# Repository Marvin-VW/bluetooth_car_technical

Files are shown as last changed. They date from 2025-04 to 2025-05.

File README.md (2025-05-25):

# 3D-Printed ESP32 RC Car – Complete Project Documentation

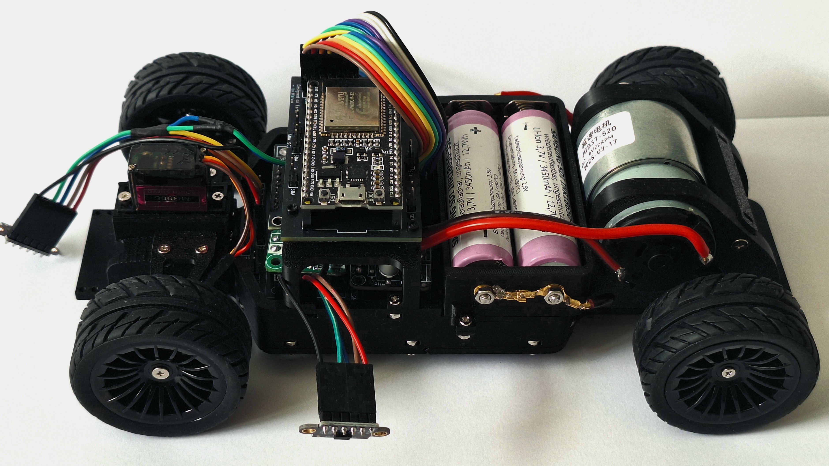
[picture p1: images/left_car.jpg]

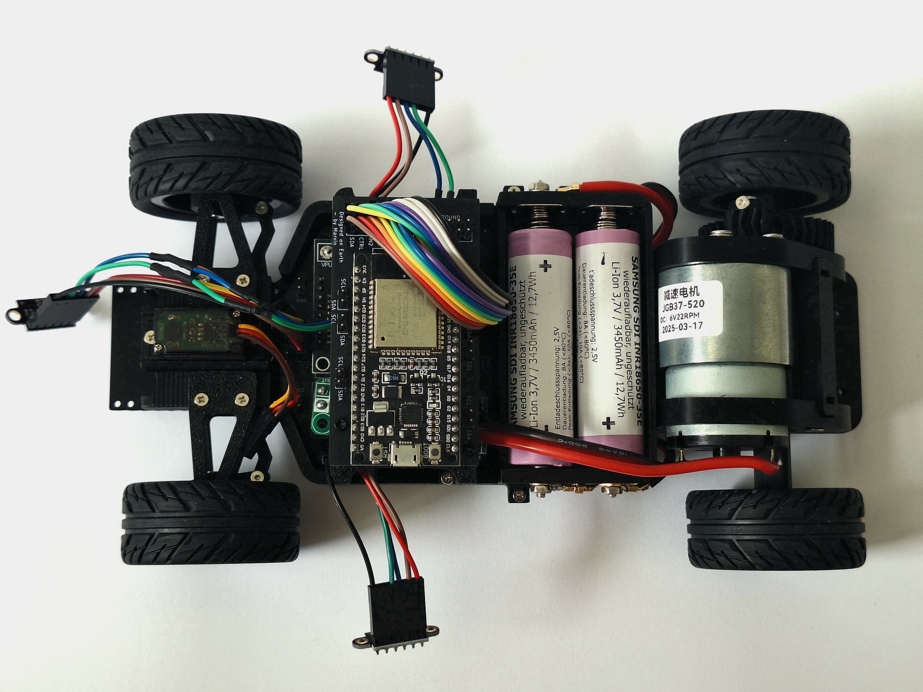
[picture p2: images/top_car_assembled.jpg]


## Project Overview
This project consists of a fully 3D-printed RC car based on an ESP32 controller, designed for remote control via a custom-built app.  
All mechanical parts, electronics (PCBs), and software components are fully self-developed or heavily customized.

The vehicle body is based on a DeLorean model (Back to the Future), which has been modified for integration of custom hardware components and a clear interior view.

---

## Features
- **Drive System**:
    - JGB37-520 Motor connected via an axle with ball bearings
    - Front axle controlled by MG90S servo
- **Distance Sensors**:
    - 3x VL53L0X laser distance sensors connected via I2C bus
- **Camera**:
    - ESP32-CAM module for live video streaming over WiFi
- **Lighting**:
    - WS2812C individually addressable LEDs for headlights, taillights, indicators, brake lights, and reverse lights
- **Battery**:
    - 2x Samsung SDI INR18650-35E 3.7V cells (combined to 7.2V system)
- **Charging**:
    - USB-C PD (Power Delivery) charging at 9V/3A via custom charging module
- **Battery Management System (BMS)**:
    - HX-2S-D20 unit for safe charging/discharging

---

## Mechanical Design
- **Chassis**: Modified base from DKS Basics, adjusted for optimized motor mounts, axle supports, battery placement, ESP32 mounting, and PCB integration.
- **Body**: DeLorean STL, modified for wheel clearance, USB-C charging access, and removal of windows for better visibility of internal components.
- **3D Printed Parts**:
    - Chassis components
    - Gear holders and servo brackets
    - Motor mounts
    - Sensor mounts
    - Battery compartments
    - LED lighting holders

---

## Bill of Materials (BOM)

| Component | Description |
|---|---|
| ESP32 | Main microcontroller |
| JGB37-520 Motor | Drive motor |
| MG90S Servo | Steering servo |
| 3x VL53L0X | Distance sensors (I2C bus) |
| 2x Samsung INR18650-35E | Battery cells |
| INA3221 | Triple current monitor |
| HX-2S-D20 | 2S BMS for battery management |
| ESP32-CAM | Camera module |
| WS2812C LED Strip | Addressable LEDs for lighting |
| Custom Power PCB | Power regulation and distribution board |
| Custom ESP32 PCB | ESP32 interface board |
| Front LED PCBs (x2 variants) | Strip & individual LED board for front lighting |
| Rear LED PCBs (x2 variants)  | Strip & individual LED board for rear lighting |
| 3D Printed Parts | Chassis, body, mounting structures |
| USB-C Charging Module | USB-PD fast charging support |
| Bearings, Gears, Shafts | Mechanical components |

---

## Repository Structure

```bash
/3d-printed-esp32-rc-car
│
├── 3d_printed_parts/             # STL files for chassis and case
│
├── pcbs/
│   ├── power_pcb/                # KiCad files and Gerbers for power management board
│   ├── esp32_pcb/                # KiCad files and Gerbers for ESP32 connection board
│   ├── lighting_pcbs/
│   │   ├── front_strip_version/  # PCB for front LED strip mounting
│   │   ├── front_single_led/     # PCB for front individual LEDs
│   │   ├── rear_strip_version/   # PCB for rear LED strip mounting
│   │   └── rear_single_led/      # PCB for rear individual LEDs
│
├── firmware/                     # (External Link: [ESP32 Firmware Repo](https://github.com/Marvin-VW/bluetooth_car_cpp))
│
├── app/                          # (External Link: [Mobile App Repo](https://github.com/Marvin-VW/spring_rest_todo_app))
│
├── images/                       # Photos, renderings, diagrams
│
└── README.md                     # This file
```

---

## Electronic Architecture

### Main Boards:
- **Power PCB**:
    - Battery management (charging/discharging)
    - 5V and 6.6V regulated outputs
    - INA3221 triple current sensor
    - Connectors for servo, distance sensors, motor
- **ESP32 PCB**:
    - Dedicated ESP32 interface
    - Connection to power PCB via a 2x7 (14-pin) connector

### Lighting Boards:
- **Front LED Boards**:
    - *LED Strip Version*: For easier integration of flexible LED strips (WS2812C-compatible)
    - *Individual LED Version*: For precise placement of discrete WS2812C LEDs
- **Rear LED Boards**:
    - *LED Strip Version*
    - *Individual LED Version*

Each lighting board is tailored to fit into designated 3D printed holders.

---

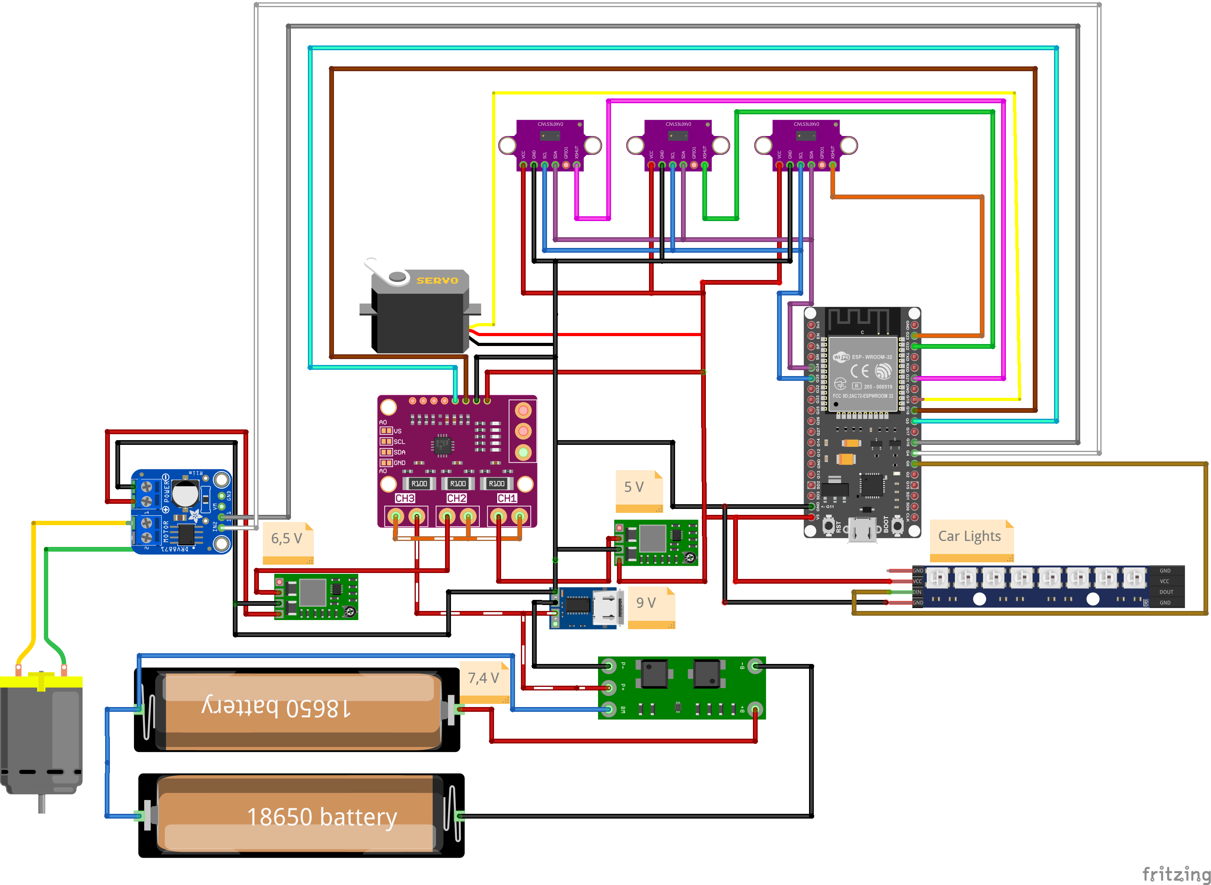
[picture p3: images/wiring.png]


Note: Pins not accurate.

---

## Build and Assembly

1. **3D Print Parts**  
   Print all required STL files using PLA or PETG for maximum durability.

2. **Assemble Electronics**
    - Solder PCBs based on provided KiCad projects.
    - Install the Power PCB, ESP32 PCB, distance sensors, and LEDs.

3. **Mechanical Assembly**
    - Mount motor, servo, and axles with ball bearings.
    - Install batteries, boards, and secure the chassis components.

4. **Install Firmware**
    - Flash the ESP32 using the firmware available in the firmware repository.

5. **App Setup**
    - Install the mobile app to control the car via WiFi.

6. **Testing and Calibration**
    - Test motor, servo, sensors, and LEDs individually before full operation.

---

## License
MIT License

---

## Contributions
Contributions, issues, and feature requests are welcome! Feel free to check the [issues page](#).

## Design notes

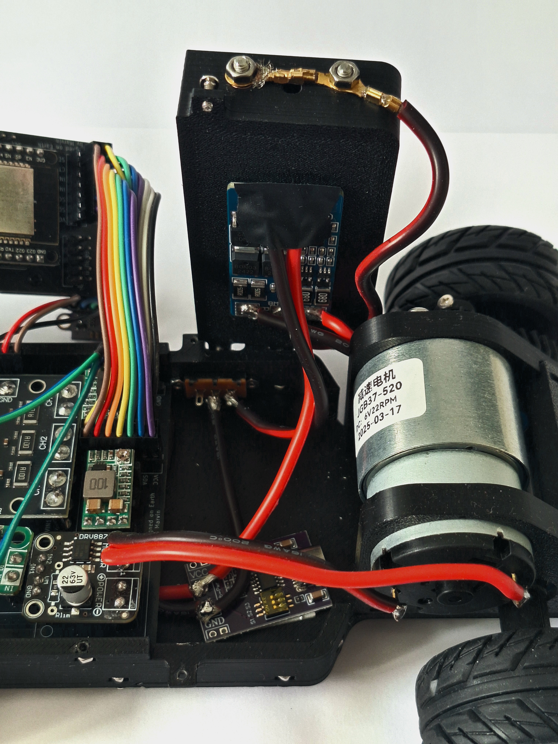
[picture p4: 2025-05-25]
images/battery_car.jpg

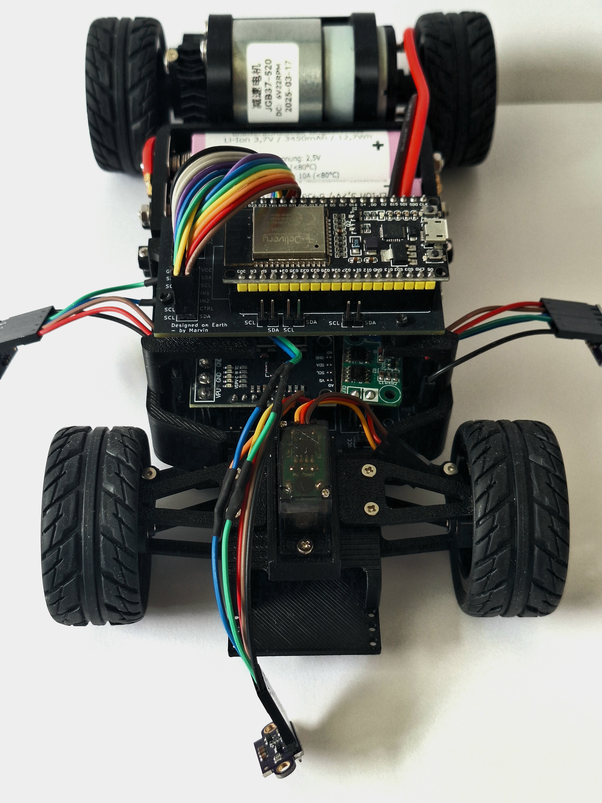
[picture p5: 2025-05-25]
images/front_car.jpg

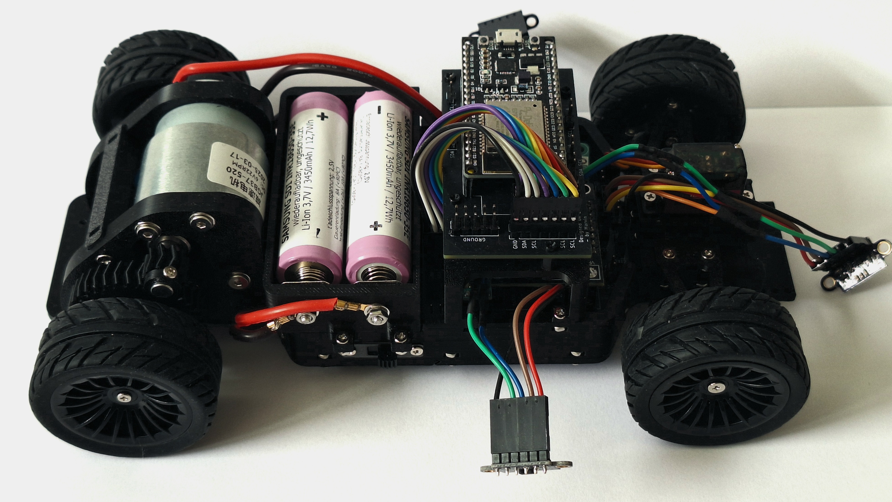
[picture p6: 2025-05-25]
images/right_car.jpg

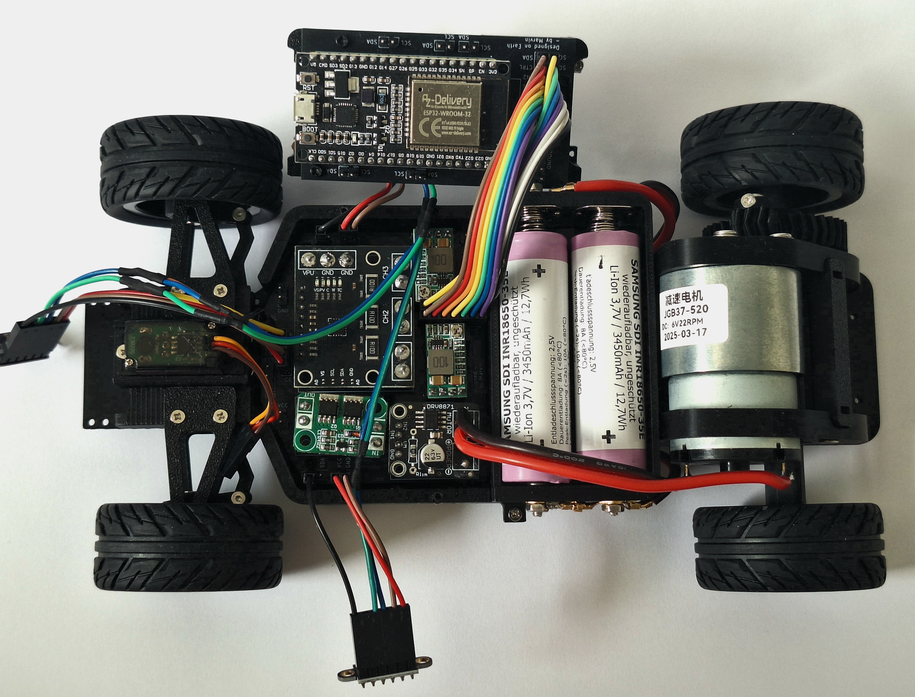
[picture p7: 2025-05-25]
images/top_car.jpg

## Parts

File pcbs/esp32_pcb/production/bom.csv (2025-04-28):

Designator | Footprint | Quantity | Value | LCSC Part #
J1, J3, J4, J5, J6 | PinHeader_1x02_P2.54mm_Vertical | 5 | Conn_01x02_Pin
J2 | PinHeader_2x07_P2.54mm_Vertical | 1 | Conn_02x07_Odd_Even
J7 | PinHeader_2x05_P2.54mm_Vertical | 1 | Conn_02x05_Odd_Even
U1 | MODULE_ESP32-DEVKITC-32E | 1 | ESP32-DEVKITC-32E

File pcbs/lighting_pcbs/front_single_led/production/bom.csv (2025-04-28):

Designator | Footprint | Quantity | Value | LCSC Part #
_2, |  | 2
J2, J3 | PinHeader_1x03_P2.54mm_Vertical | 2 | Conn_01x03
U1, U10, U11, U12, U13, U14, U15, U16, U2, U3, U4, U5, U6, U7, U8, U9 | LED_WS2812C-2020 | 16 | WS2812C-2020

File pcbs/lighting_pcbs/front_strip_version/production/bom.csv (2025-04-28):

Designator | Footprint | Quantity | Value | LCSC Part #
_2, |  | 2
J1, J2, J3, J4, J5, J6, J7, J8 | led_pads | 8 | Conn_01x03_Pin
J10, J9 | PinHeader_1x03_P2.54mm_Vertical | 2 | Conn_01x03_Pin

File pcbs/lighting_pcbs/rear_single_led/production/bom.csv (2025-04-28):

Designator | Footprint | Quantity | Value | LCSC Part #
_2, |  | 2
J1, J3 | PinHeader_1x03_P2.54mm_Vertical | 2 | Conn_01x03_Pin
U1, U14, U15, U16, U17, U18, U19, U2, U20, U3, U4, U5, U6, U7 | LED_WS2812C-2020 | 14 | WS2812C-2020

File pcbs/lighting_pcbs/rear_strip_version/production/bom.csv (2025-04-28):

Designator | Footprint | Quantity | Value | LCSC Part #
J1, J2, J5, J6 | led_pads | 4 | Conn_01x03_Pin
J10, J9 | PinHeader_1x03_P2.54mm_Vertical | 2 | Conn_01x03_Pin

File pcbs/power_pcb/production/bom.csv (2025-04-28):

Designator | Footprint | Quantity | Value | LCSC Part #
_3, _2, |  | 3
J1, J14, J25 | PinHeader_1x04_P2.54mm_Vertical | 3 | Conn_01x04_Pin
J13, J20, J22, J23, J26, J27, J3 | PinHeader_1x02_P2.54mm_Vertical | 7 | Conn_01x02_Pin
J2 | PinHeader_2x07_P2.54mm_Vertical | 1 | Conn_02x07_Odd_Even
J21, J24 | PinHeader_1x03_P2.54mm_Vertical | 2 | Conn_01x03_Pin
U1 | anti_reverse | 1 | ~
U2 | DRV8871 | 1 | ~
U4 | INA3221_Module | 1 | ~

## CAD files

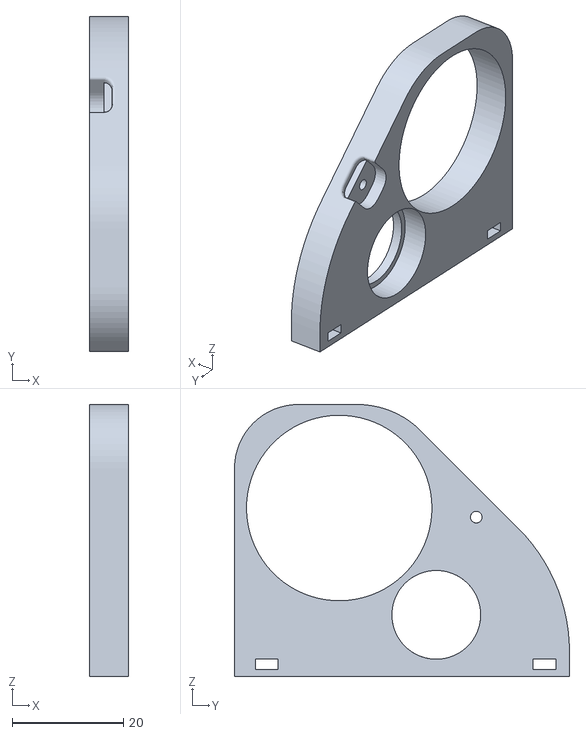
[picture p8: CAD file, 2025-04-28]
chassis/stl/105_Chassis v105_Motor-Frame_L.stl
7.00 x 60.4 x 49.0

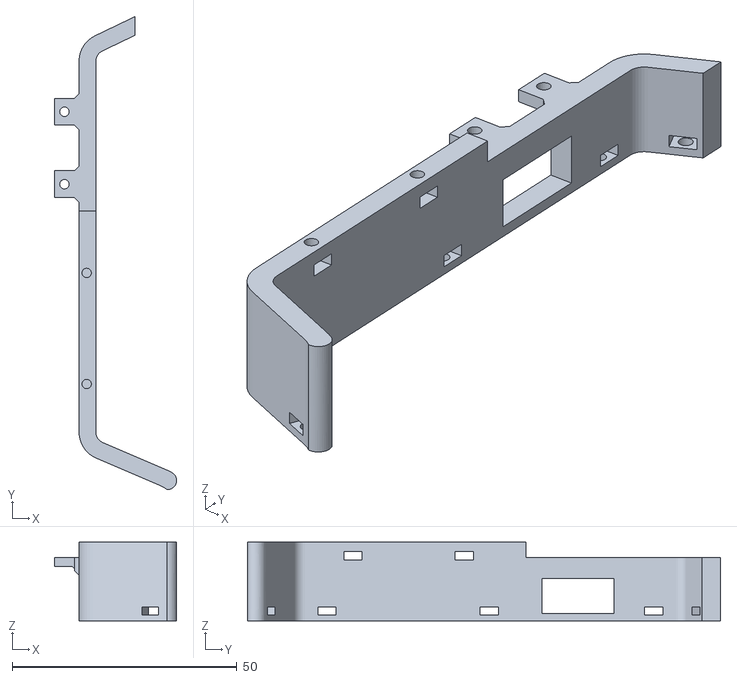
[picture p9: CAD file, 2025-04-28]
chassis/stl/105_Chassis v105_Body_R.stl
27.2 x 105.2 x 17.5

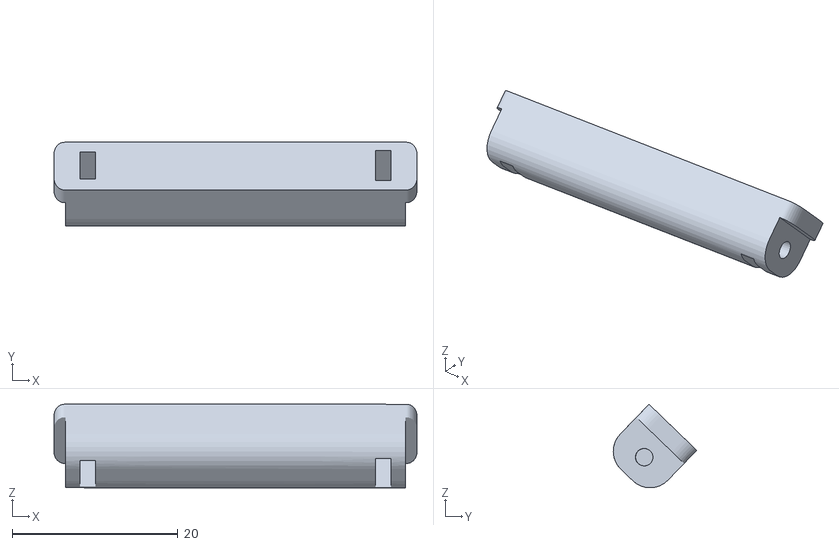
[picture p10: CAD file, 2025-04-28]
chassis/stl/105_Chassis v105_Motor-Frame_Backing.stl
43.8 x 10.1 x 10.1

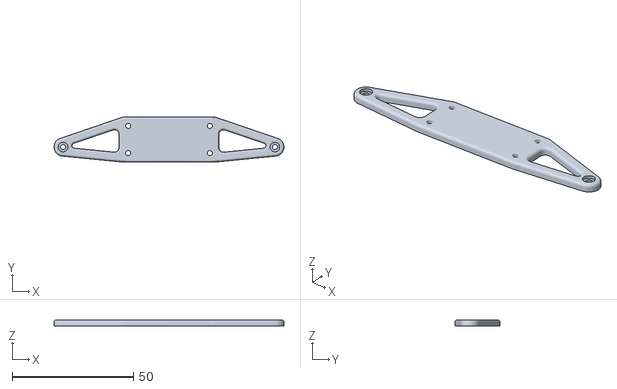
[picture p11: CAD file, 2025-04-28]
chassis/stl/105_Chassis v105_Front-Bars-Lower.stl
95.0 x 18.8 x 2.50

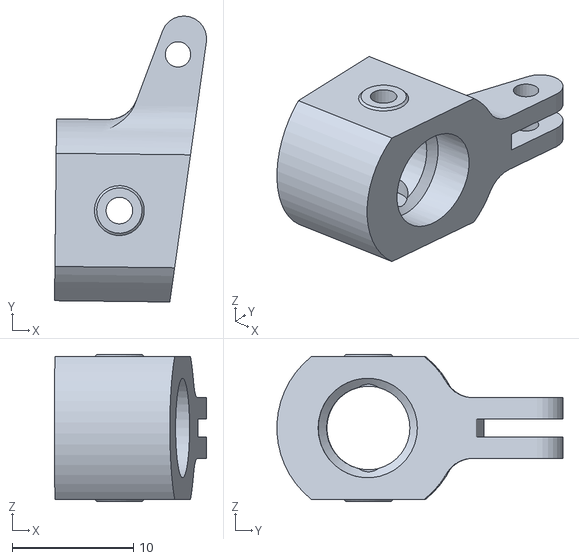
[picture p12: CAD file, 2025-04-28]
chassis/stl/105_Chassis v105_Wheel-Hub_R.stl
12.5 x 23.6 x 12.1

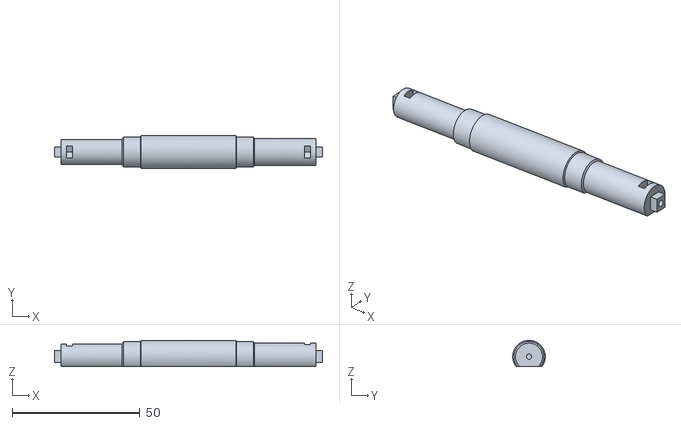
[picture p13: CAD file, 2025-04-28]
chassis/stl/105_Chassis v105_Rear-Axis.stl
105.0 x 12.8 x 10.3

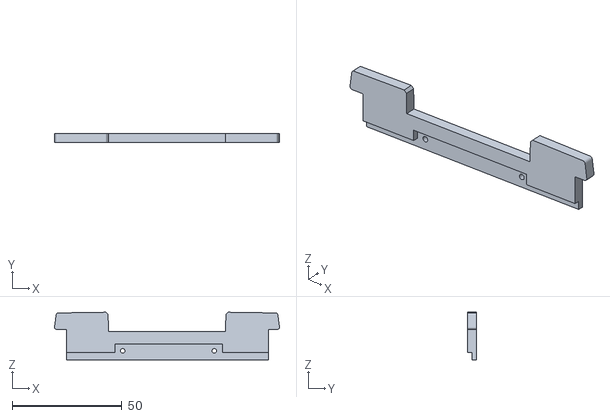
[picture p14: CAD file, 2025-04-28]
chassis/stl/105_Chassis v105_stripe_holder_front.stl
102.7 x 4.00 x 21.7

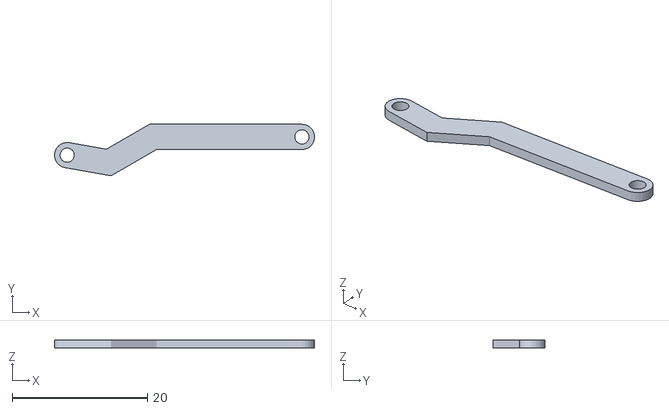
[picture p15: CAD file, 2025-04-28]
chassis/stl/105_Chassis v105_Steering_L.stl
38.4 x 7.62 x 1.25

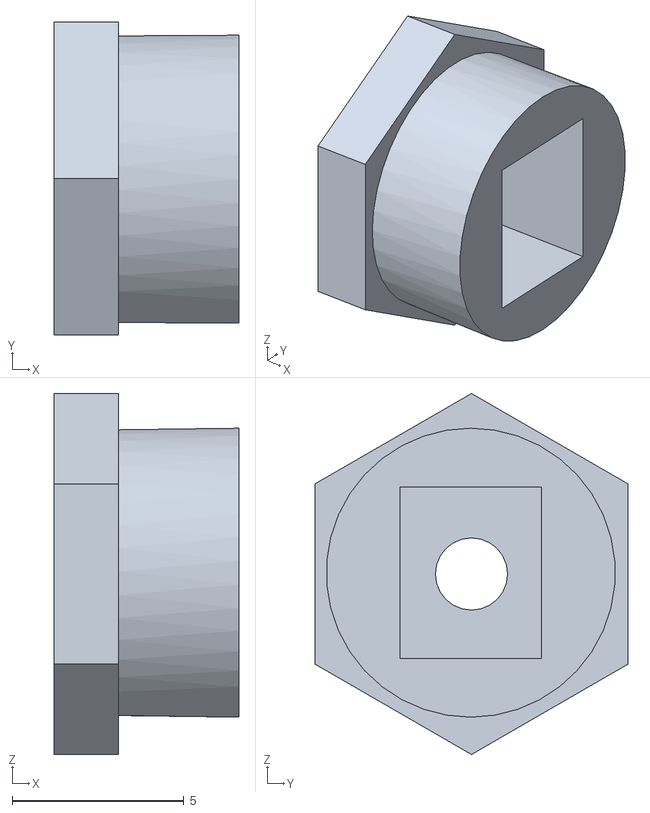
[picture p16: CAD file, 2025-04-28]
chassis/stl/105_Chassis v105_Wheel-Axis_R.stl
5.38 x 9.09 x 10.5

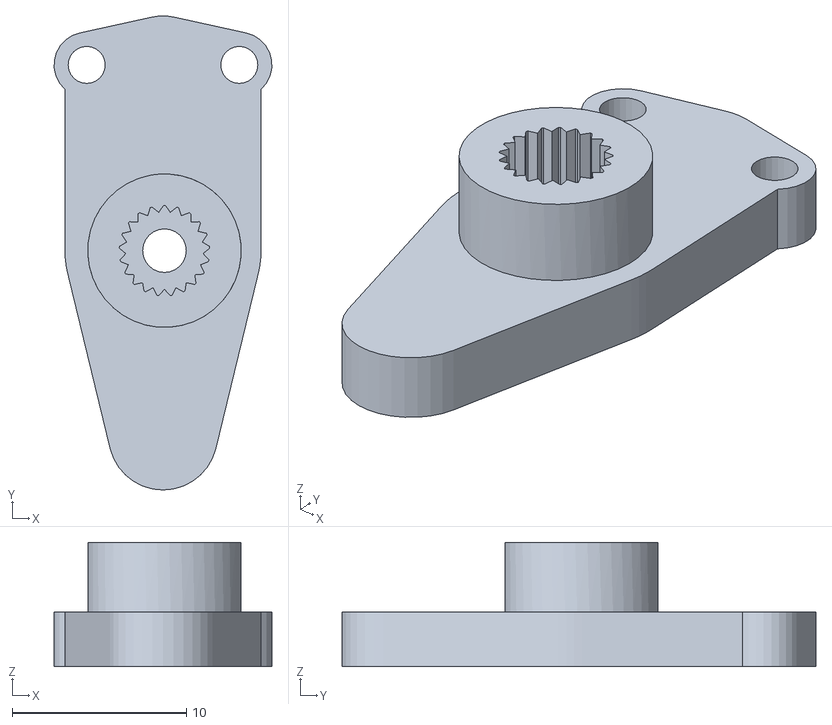
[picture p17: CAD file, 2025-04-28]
chassis/stl/105_Chassis v105_Servo_Horn.stl
12.5 x 27.2 x 7.12

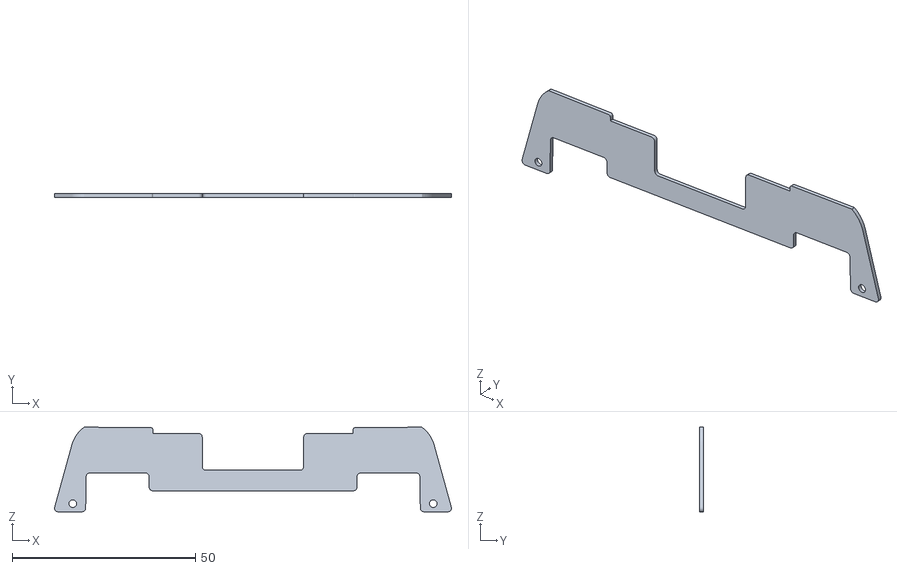
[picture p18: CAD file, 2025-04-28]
chassis/stl/105_Chassis v105_stripe_holder_back.stl
108.3 x 1.00 x 23.1

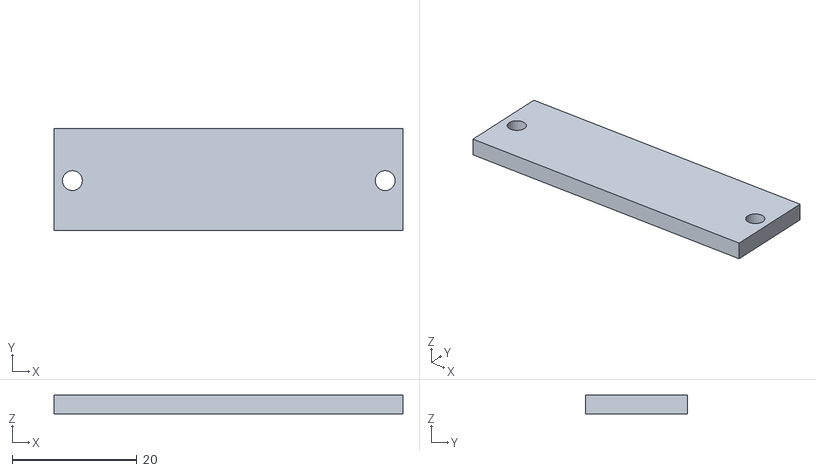
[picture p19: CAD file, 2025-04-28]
chassis/stl/105_Chassis v105_Car_Holder_Front(2).stl
55.9 x 16.4 x 3.00

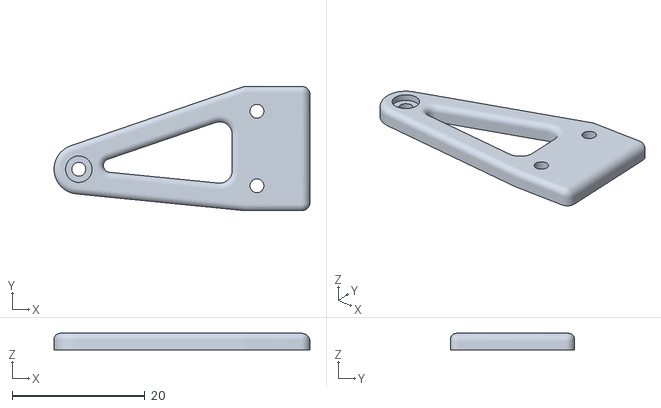
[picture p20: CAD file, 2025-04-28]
chassis/stl/105_Chassis v105_Front-Bars-Upper_R.stl
38.6 x 18.8 x 2.50

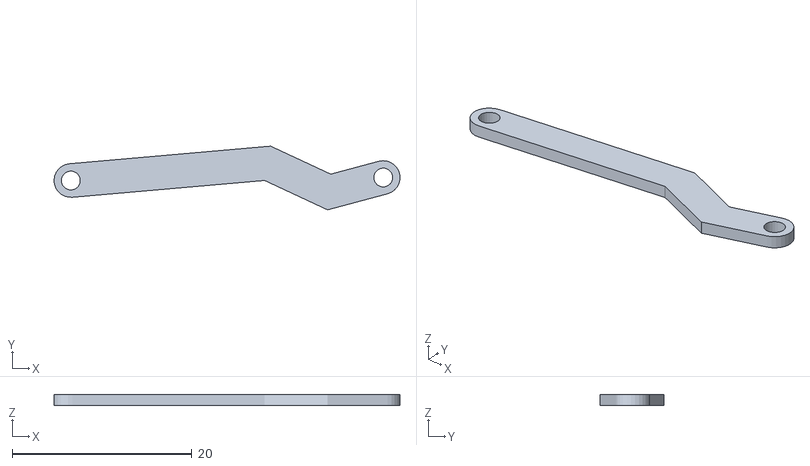
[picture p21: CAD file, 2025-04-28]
chassis/stl/105_Chassis v105_Steering_R.stl
38.5 x 7.10 x 1.25

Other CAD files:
chassis/stl/105_Chassis v105_Body_L.stl
chassis/stl/105_Chassis v105_gear_motor_1.stl
chassis/stl/105_Chassis v105_Front-Bars-Upper_L.stl
chassis/stl/105_Chassis v105_Chassis_Front.stl
chassis/fusion360/Chassis.f3z
chassis/stl/105_Chassis v105_Car_Holder_Back.stl
chassis/stl/105_Chassis v105_Car_Holder_Front(1).stl
chassis/stl/105_Chassis v105_Chassis_Back.stl
chassis/stl/105_Chassis v105_ESP_Holder.stl
chassis/stl/105_Chassis v105_Motor-Frame_R.stl
chassis/stl/105_Chassis v105_Wheel-Axis-Nut.stl
chassis/stl/105_Chassis v105_Wheel-Axis_Front.stl
chassis/stl/105_Chassis v105_Wheel-Axis_L.stl
chassis/stl/105_Chassis v105_Wheel-Hub_L.stl
chassis/stl/105_Chassis v105_battery_18650_x2.stl

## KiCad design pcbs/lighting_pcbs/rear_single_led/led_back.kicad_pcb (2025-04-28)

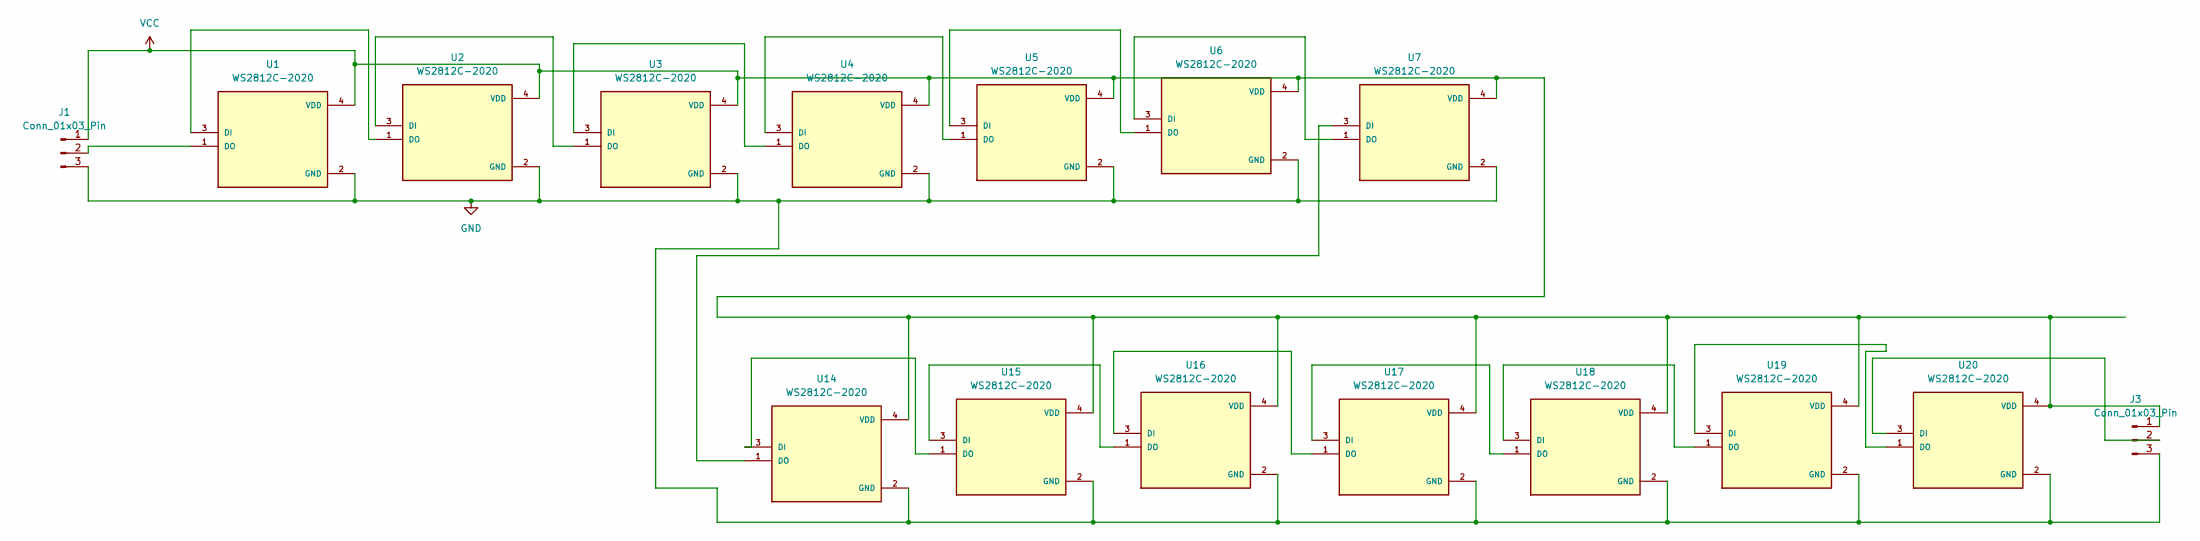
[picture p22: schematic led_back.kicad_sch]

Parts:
J1, J3: Conn_01x03_Pin; PinHeader_1x03_P2.54mm_Vertical
U1, U2, U3, U4, U5, U6, U7, U14, U15, U16, U17, U18, U19, U20: WS2812C-2020; LED_WS2812C-2020; PARTREV V1.0

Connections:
GND: J1.3, J3.3, U1.2 (GND), U2.2 (GND), U3.2 (GND), U4.2 (GND), U5.2 (GND), U6.2 (GND), U7.2 (GND), U14.2 (GND), U15.2 (GND), U16.2 (GND), U17.2 (GND), U18.2 (GND), U19.2 (GND), U20.2 (GND)
unnamed: J1.2, U1.1 (DO)
unnamed: J3.2, U20.3 (DI)
unnamed: U1.3 (DI), U2.1 (DO)
unnamed: U2.3 (DI), U3.1 (DO)
unnamed: U3.3 (DI), U4.1 (DO)
unnamed: U4.3 (DI), U5.1 (DO)
unnamed: U5.3 (DI), U6.1 (DO)
unnamed: U6.3 (DI), U7.1 (DO)
unnamed: U14.3 (DI), U15.1 (DO)
unnamed: U7.3 (DI), U14.1 (DO)
unnamed: U15.3 (DI), U16.1 (DO)
unnamed: U16.3 (DI), U17.1 (DO)
unnamed: U17.3 (DI), U18.1 (DO)
unnamed: U18.3 (DI), U19.1 (DO)
unnamed: U19.3 (DI), U20.1 (DO)
VCC: J1.1, J3.1, U1.4 (VDD), U2.4 (VDD), U3.4 (VDD), U4.4 (VDD), U5.4 (VDD), U6.4 (VDD), U7.4 (VDD), U14.4 (VDD), U15.4 (VDD), U16.4 (VDD), U17.4 (VDD), U18.4 (VDD), U19.4 (VDD), U20.4 (VDD)

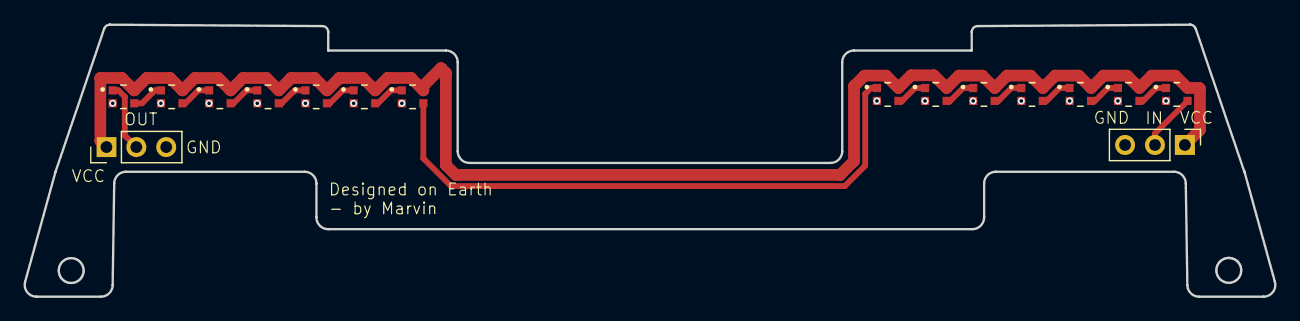
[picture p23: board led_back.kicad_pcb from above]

Board: 2 copper layers, 106.2 x 23.1 mm, 16 parts (0 on the bottom side), 17 nets.

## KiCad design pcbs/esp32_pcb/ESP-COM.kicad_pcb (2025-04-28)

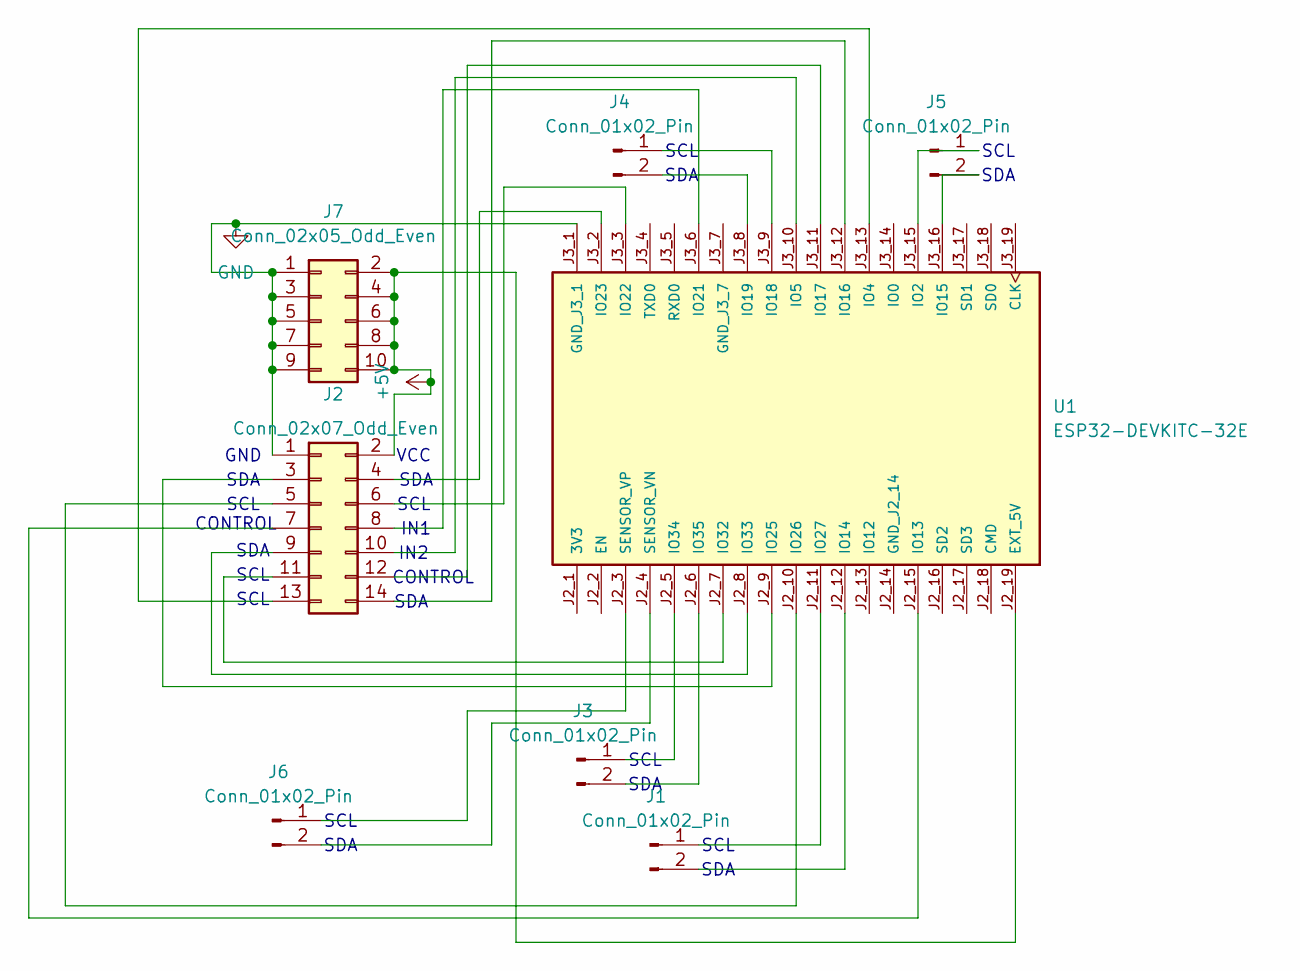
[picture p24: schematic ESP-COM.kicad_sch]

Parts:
J1, J3, J4, J5, J6: Conn_01x02_Pin; PinHeader_1x02_P2.54mm_Vertical
J2: Conn_02x07_Odd_Even; PinHeader_2x07_P2.54mm_Vertical
J7: Conn_02x05_Odd_Even; PinHeader_2x05_P2.54mm_Vertical
U1: ESP32-DEVKITC-32E; MODULE_ESP32-DEVKITC-32E; PARTREV 1.4

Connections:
+5V: J2.2, J7.2, J7.4, J7.6, J7.8, J7.10, U1.J2_19 (EXT_5V)
GND: J2.1, J7.1, J7.3, J7.5, J7.7, J7.9, U1.J3_1 (GND_J3_1)
unnamed: J1.1, U1.J2_11 (IO27)
unnamed: J1.2, U1.J2_12 (IO14)
unnamed: J2.3, U1.J2_9 (IO25)
unnamed: J2.4, U1.J3_2 (IO23)
unnamed: J2.5, U1.J2_10 (IO26)
unnamed: J2.6, U1.J3_3 (IO22)
unnamed: J2.7, U1.J2_15 (IO13)
unnamed: J2.8, U1.J3_6 (IO21)
unnamed: J2.9, U1.J2_8 (IO33)
unnamed: J2.10, U1.J3_10 (IO5)
unnamed: J2.11, U1.J2_7 (IO32)
unnamed: J2.12, U1.J3_11 (IO17)
unnamed: J2.13, U1.J3_13 (IO4)
unnamed: J2.14, U1.J3_12 (IO16)
unnamed: J3.1, U1.J2_5 (IO34)
unnamed: J3.2, U1.J2_6 (IO35)
unnamed: J4.1, U1.J3_9 (IO18)
unnamed: J4.2, U1.J3_8 (IO19)
unnamed: J5.1, U1.J3_15 (IO2)
unnamed: J5.2, U1.J3_16 (IO15)
unnamed: J6.1, U1.J2_3 (SENSOR_VP)
unnamed: J6.2, U1.J2_4 (SENSOR_VN)

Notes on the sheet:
SDA
SCL
IN1
CONTROL
GND
VCC
IN2

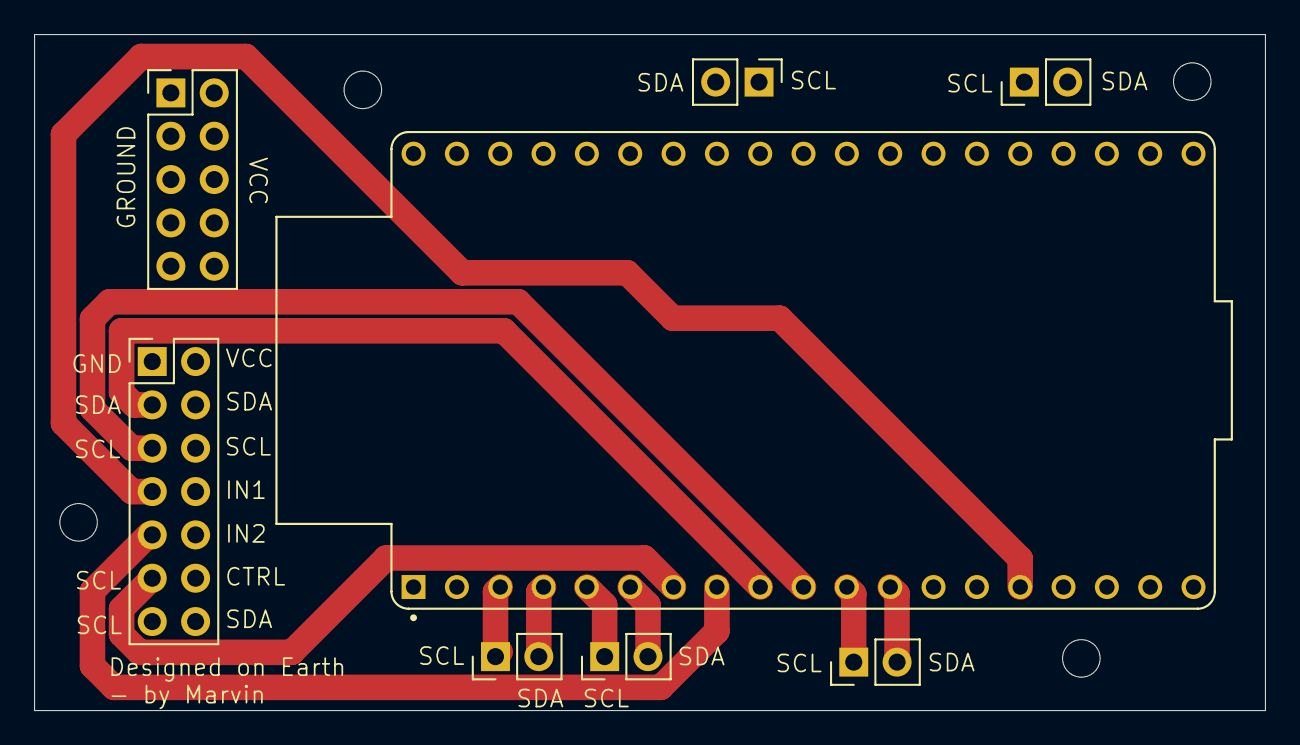
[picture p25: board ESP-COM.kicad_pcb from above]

Board: 4 copper layers, 72.1 x 39.6 mm, 8 parts (0 on the bottom side), 24 nets.

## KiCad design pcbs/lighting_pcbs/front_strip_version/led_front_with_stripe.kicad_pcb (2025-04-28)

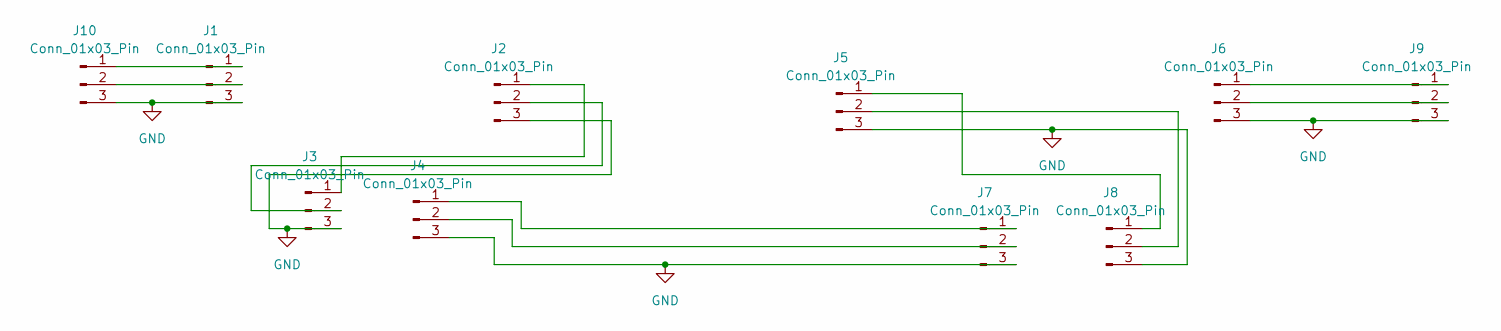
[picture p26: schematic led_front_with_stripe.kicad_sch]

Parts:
J1, J2, J3, J4, J5, J6, J7, J8: Conn_01x03_Pin; led_pads
J9, J10: Conn_01x03_Pin; PinHeader_1x03_P2.54mm_Vertical

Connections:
GND: J1.3, J2.3, J3.3, J4.3, J5.3, J6.3, J7.3, J8.3, J9.3, J10.3
unnamed: J1.1, J10.1
unnamed: J1.2, J10.2
unnamed: J2.1, J3.1
unnamed: J2.2, J3.2
unnamed: J4.1, J7.1
unnamed: J4.2, J7.2
unnamed: J5.1, J8.1
unnamed: J5.2, J8.2
unnamed: J6.1, J9.1
unnamed: J6.2, J9.2

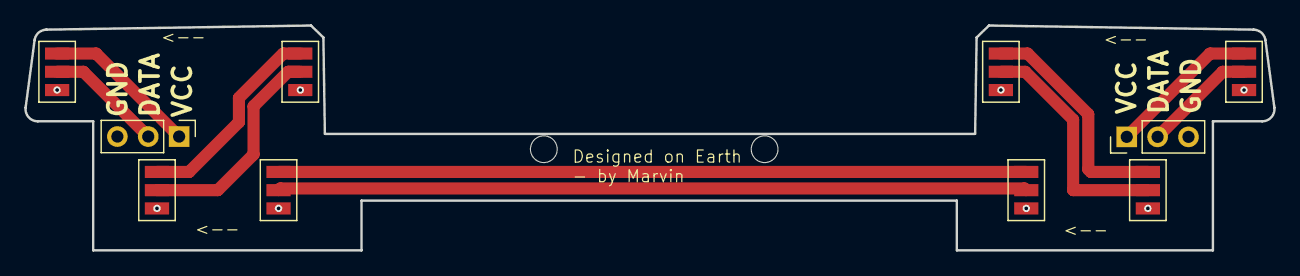
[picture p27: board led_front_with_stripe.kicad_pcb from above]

Board: 2 copper layers, 102.7 x 18.5 mm, 10 parts (0 on the bottom side), 11 nets.

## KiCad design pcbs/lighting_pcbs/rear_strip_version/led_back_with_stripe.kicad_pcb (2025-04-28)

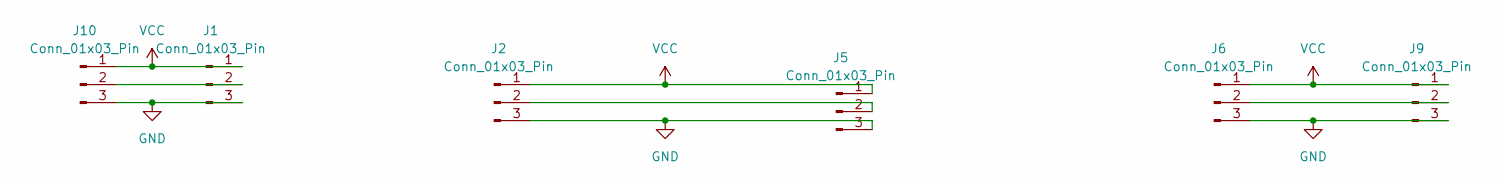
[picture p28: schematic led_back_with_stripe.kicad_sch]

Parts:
J1, J2, J5, J6: Conn_01x03_Pin; led_pads
J9, J10: Conn_01x03_Pin; PinHeader_1x03_P2.54mm_Vertical

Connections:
GND: J1.3, J2.3, J5.3, J6.3, J9.3, J10.3
unnamed: J1.2, J10.2
unnamed: J2.2, J5.2
unnamed: J6.2, J9.2
VCC: J1.1, J2.1, J5.1, J6.1, J9.1, J10.1

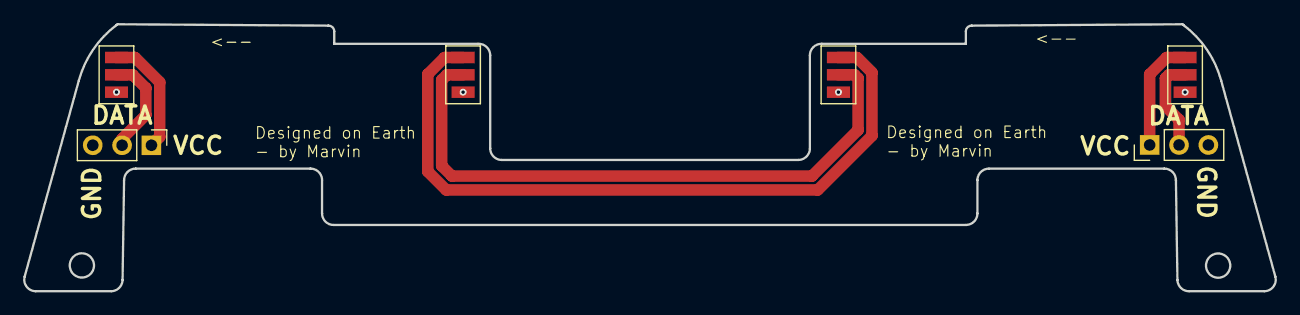
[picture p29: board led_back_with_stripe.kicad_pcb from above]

Board: 2 copper layers, 108.3 x 23.1 mm, 6 parts (0 on the bottom side), 5 nets.

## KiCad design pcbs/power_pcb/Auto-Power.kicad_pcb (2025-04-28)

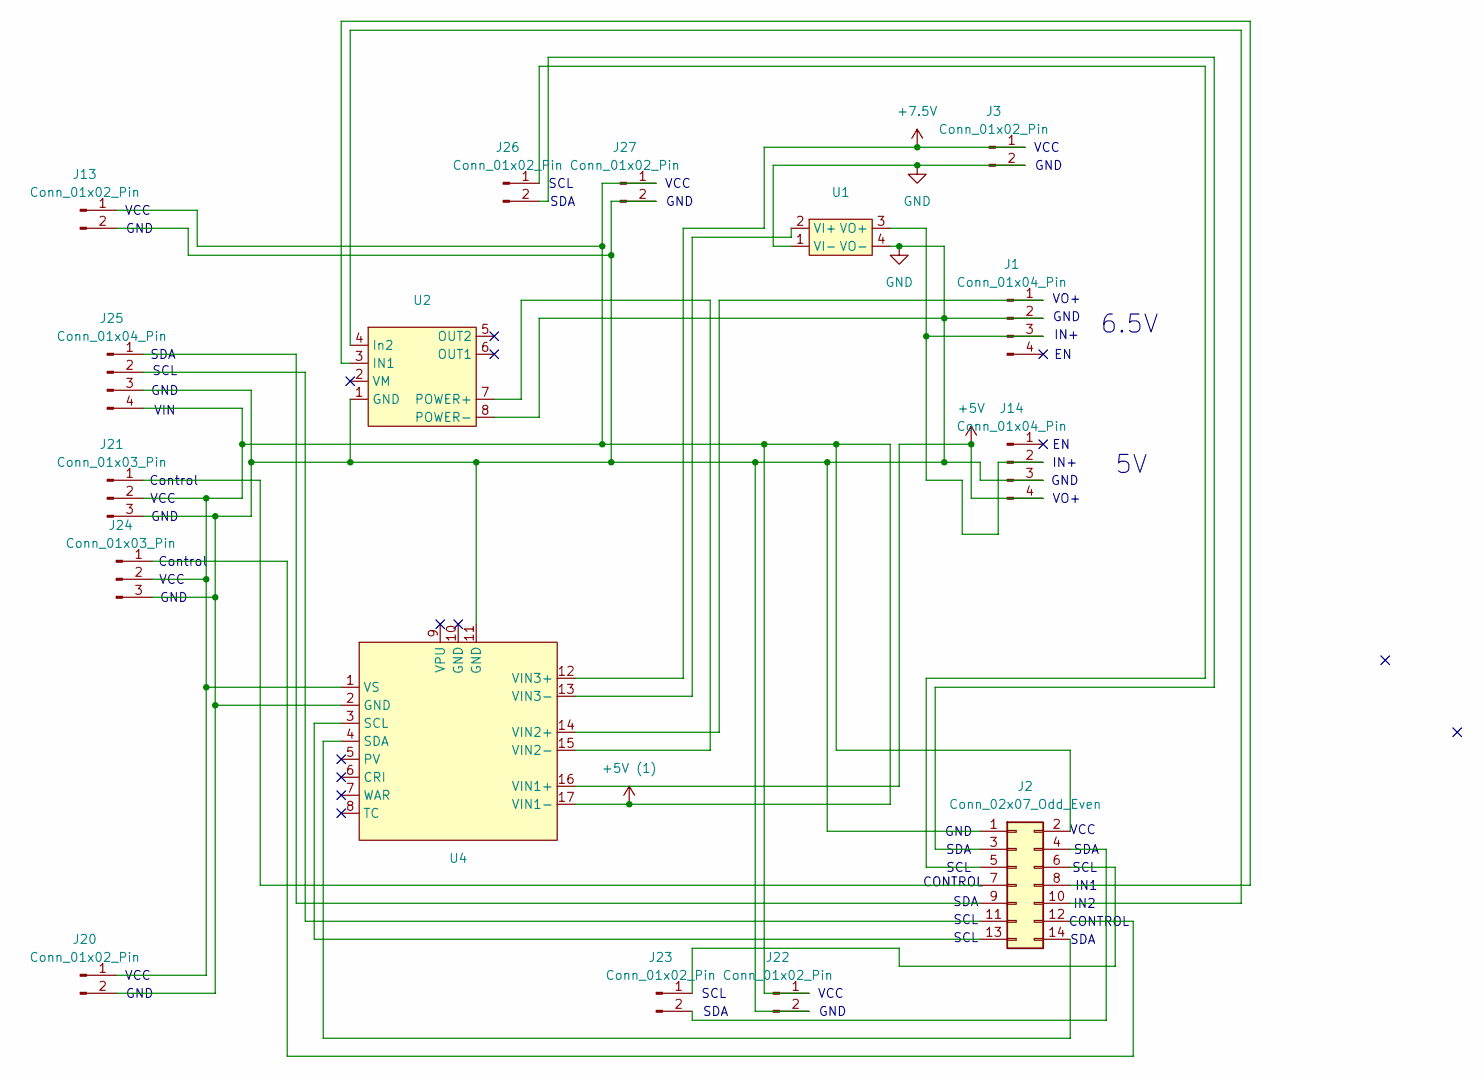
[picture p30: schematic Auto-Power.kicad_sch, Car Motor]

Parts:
J1, J14, J25: Conn_01x04_Pin; PinHeader_1x04_P2.54mm_Vertical
J2: Conn_02x07_Odd_Even; PinHeader_2x07_P2.54mm_Vertical
J3, J13, J20, J22, J23, J26, J27: Conn_01x02_Pin; PinHeader_1x02_P2.54mm_Vertical
J21, J24: Conn_01x03_Pin; PinHeader_1x03_P2.54mm_Vertical
U1: anti_reverse
U2: DRV8871
U4: INA3221_Module

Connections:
+5V: J14.4, U4.16 (VIN1+)
+5V (1): J2.2, J13.1, J20.1, J21.2, J22.1, J24.2, J25.4, J27.1, U4.1 (VS), U4.17 (VIN1-)
+7.5V: J3.1, U4.12 (VIN3+)
GND: J1.2, J2.1, J3.2, J13.2, J14.3, J20.2, J21.3, J22.2, J24.3, J25.3, J27.2, U1.1 (VI-), U1.4 (VO-), U2.1 (GND), U2.8 (POWER-), U4.2 (GND), U4.11 (GND)
unnamed: J1.1, U4.14 (VIN2+)
unnamed: J1.3, J14.2, U1.3 (VO+)
unnamed: J2.3, J26.2
unnamed: J2.4, J23.2
unnamed: J2.5, J26.1
unnamed: J2.6, J23.1
unnamed: J2.7, J21.1
unnamed: J2.8, U2.3 (IN1)
unnamed: J2.9, J25.1
unnamed: J2.10, U2.4 (In2)
unnamed: J2.11, J25.2
unnamed: J2.12, J24.1
unnamed: J2.13, U4.3 (SCL)
unnamed: J2.14, U4.4 (SDA)
unnamed: U1.2 (VI+), U4.13 (VIN3-)
unnamed: U2.7 (POWER+), U4.15 (VIN2-)

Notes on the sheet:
IN2
VCC
SDA
SCL
VIN
VO+
GND
CONTROL
IN+
Control
SCL
6.5V
IN1

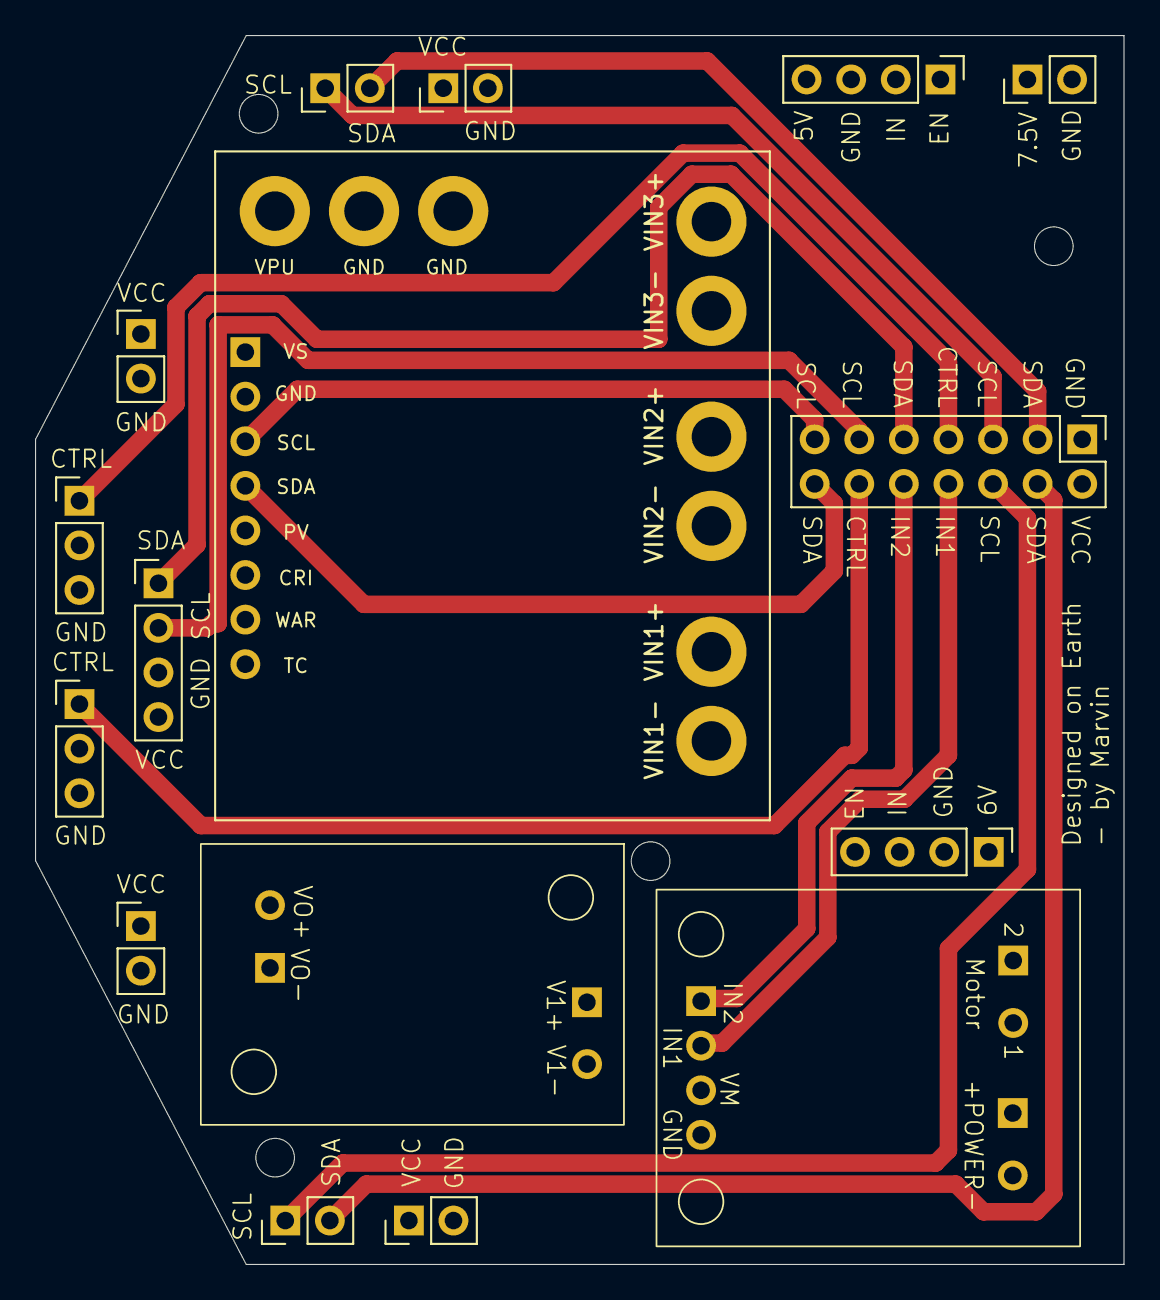
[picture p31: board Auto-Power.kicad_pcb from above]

Board: 4 copper layers, 62.0 x 70.0 mm, 16 parts (0 on the bottom side), 20 nets.

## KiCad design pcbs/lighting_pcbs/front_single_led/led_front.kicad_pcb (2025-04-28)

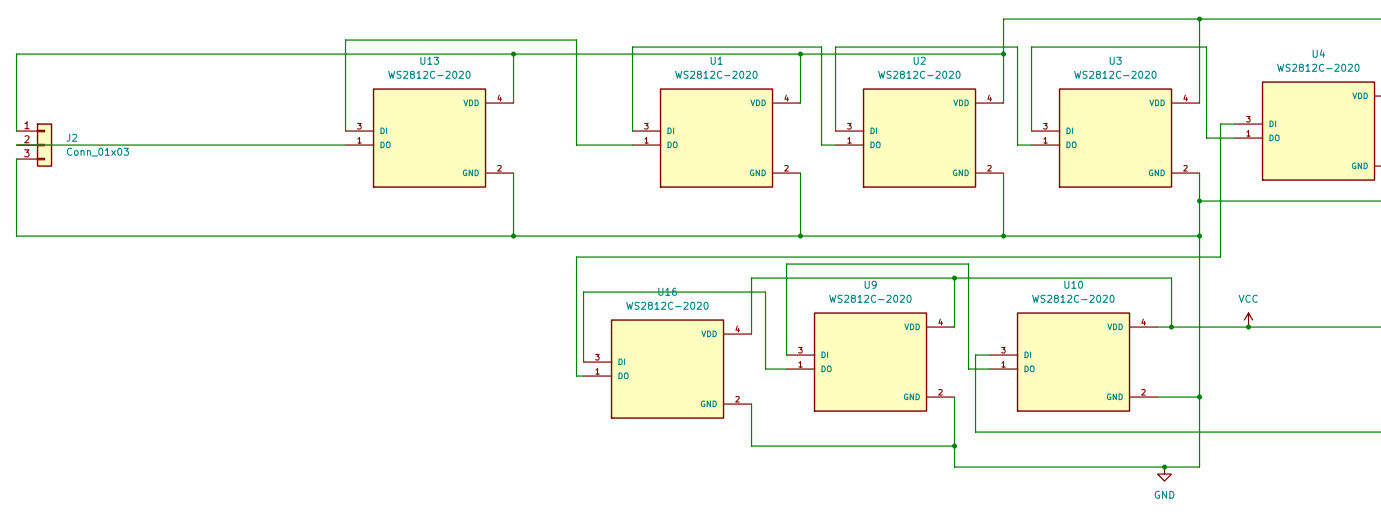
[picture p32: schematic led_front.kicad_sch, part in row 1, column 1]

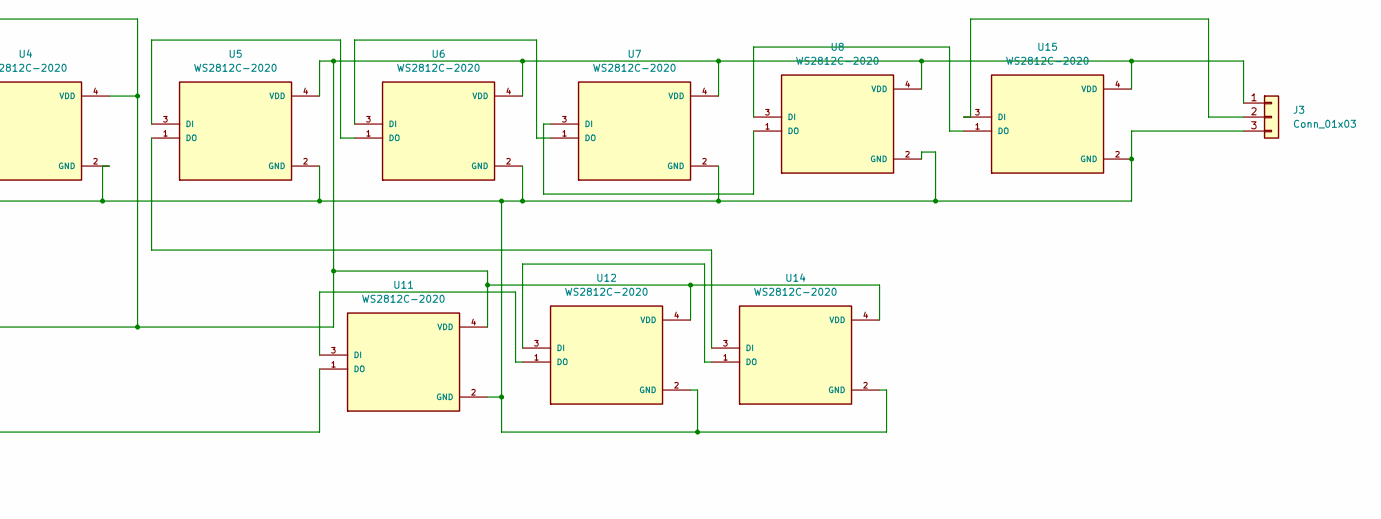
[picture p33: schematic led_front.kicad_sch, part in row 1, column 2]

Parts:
J2, J3: Conn_01x03; PinHeader_1x03_P2.54mm_Vertical
U1, U2, U3, U4, U5, U6, U7, U8, U9, U10, U11, U12, U13, U14, U15, U16: WS2812C-2020; LED_WS2812C-2020; PARTREV V1.0

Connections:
GND: J2.3, J3.3, U1.2 (GND), U2.2 (GND), U3.2 (GND), U4.2 (GND), U5.2 (GND), U6.2 (GND), U7.2 (GND), U8.2 (GND), U9.2 (GND), U10.2 (GND), U11.2 (GND), U12.2 (GND), U13.2 (GND), U14.2 (GND), U15.2 (GND), U16.2 (GND)
unnamed: J2.2, U13.1 (DO)
unnamed: J3.2, U15.3 (DI)
unnamed: U1.3 (DI), U2.1 (DO)
unnamed: U1.1 (DO), U13.3 (DI)
unnamed: U2.3 (DI), U3.1 (DO)
unnamed: U3.3 (DI), U4.1 (DO)
unnamed: U5.3 (DI), U6.1 (DO)
unnamed: U6.3 (DI), U7.1 (DO)
unnamed: U7.3 (DI), U8.1 (DO)
unnamed: U10.3 (DI), U11.1 (DO)
unnamed: U9.3 (DI), U10.1 (DO)
unnamed: U11.3 (DI), U12.1 (DO)
unnamed: U12.3 (DI), U14.1 (DO)
unnamed: U5.1 (DO), U14.3 (DI)
unnamed: U8.3 (DI), U15.1 (DO)
unnamed: U9.1 (DO), U16.3 (DI)
unnamed: U4.3 (DI), U16.1 (DO)
VCC: J2.1, J3.1, U1.4 (VDD), U2.4 (VDD), U3.4 (VDD), U4.4 (VDD), U5.4 (VDD), U6.4 (VDD), U7.4 (VDD), U8.4 (VDD), U9.4 (VDD), U10.4 (VDD), U11.4 (VDD), U12.4 (VDD), U13.4 (VDD), U14.4 (VDD), U15.4 (VDD), U16.4 (VDD)


Board: 2 copper layers, 102.7 x 18.5 mm, 18 parts (0 on the bottom side), 19 nets.
